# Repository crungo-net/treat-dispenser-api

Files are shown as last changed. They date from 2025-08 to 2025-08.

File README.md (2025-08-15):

# Treat Dispenser API

A simple REST API for controlling a treat dispenser, built with [Axum](https://github.com/tokio-rs/axum) and async Rust, and dedicated to my two rabbits.

## Table of Contents

- [Features](#features)
- [3D Printing](#3d-printing)
- [Hardware Requirements](#hardware-requirements)
- [Quick Setup](#quick-setup)
- [Installation](#installation)
- [Debian Package (Raspberry Pi, ARM64)](#debian-package-raspberry-pi-arm64)
- [Configuration](#configuration)
- [Environment Variables](#environment-variables)
- [Justfile Commands](#justfile-commands)
- [Endpoints](#endpoints)
- [Hardware Integration](#hardware-integration)
- [Logging](#logging)
- [Code Structure](#code-structure)
- [Power Monitoring (INA219 Support)](#power-monitoring-ina219-support)
- [Weight Sensor (HX711 Support)](#weight-sensor-hx711-support)
- [Testing](#testing)
- [Continuous Integration (CI)](#continuous-integration-ci)
- [GitLab and GitHub: Why Both?](#gitlab-and-github-why-both)
- [Roadmap](#roadmap)
- [License](#license)

## Features

- **One-click treat dispensing:** Trigger treat dispensing remotely via a simple REST API call.
- **Secure access with JWT authentication:** Only authorized users can dispense treats or access sensitive endpoints.
- **Real-time status monitoring:** Instantly check dispenser health, motor status, uptime, power usage, and remaining treat weight.
- **Live power and current monitoring:** View live voltage, current, and power usage for hardware safety and diagnostics.
- **Weight monitoring with HX711 load cell:** Live grams remaining exposed in `/status`, with tare and scale calibration via `/tare` and `/calibrate` (calibration persisted on disk).
- **Automatic jam and error detection:** Detects jams, over‑current, and calibration failures; can cancel operations to protect hardware.
- **Pluggable hardware via config.yaml:** Select motor, power sensor, and weight sensor implementations without recompiling.
- **Supports multiple stepper motors:** Easily switch between 28BYJ-48, NEMA-14, or mock motors.
- **Configurable cooldown & current limits:** Prevent overheating or over‑current conditions.
- **Easy setup & deployment:** Debian package, Docker, and simple YAML configuration.
- **Structured logging and diagnostics.**
- **Web and mobile friendly.**

<p align="center">
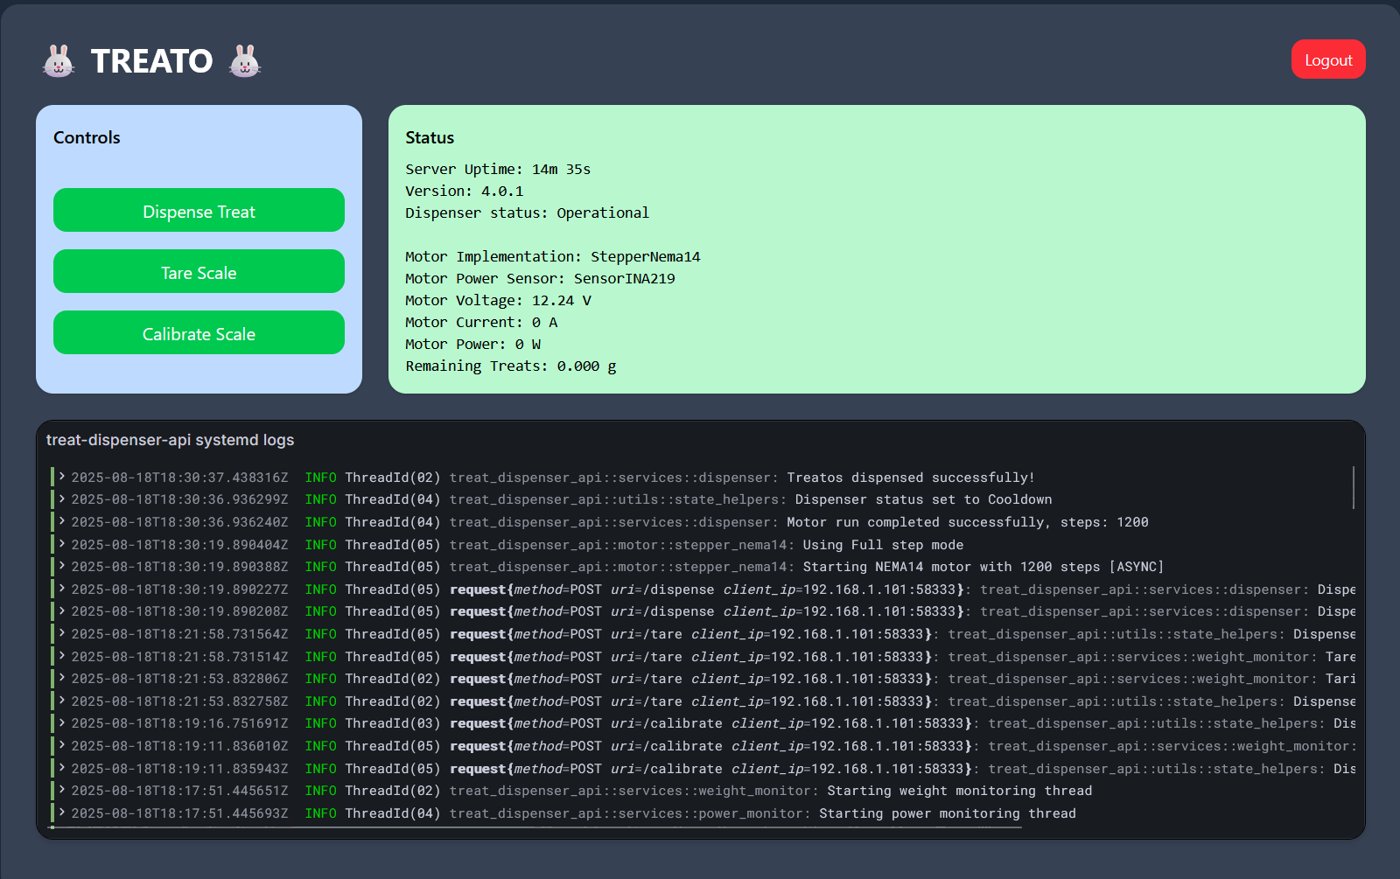
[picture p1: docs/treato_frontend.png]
Sample Treat Dispenser Frontend
  
</p>
<p align="center"><em>Simple monitoring frontend for the treat dispenser built with React (see <code>treat-dispenser-frontend</code> for source)</em></p>

## 3D Printing

STL files for 3D printing the dispenser hardware are available in the `3d_printing` folder of this repository. These models are heavily modified and based on the original pellet dispenser designs by [jackpkenn](https://github.com/jackpkenn/PelletDispenser/tree/master). Please review and adapt as needed for your hardware setup.

## Hardware Requirements

This project is designed to work with the following hardware:

- **NEMA14 stepper motor** (with A4988 or compatible driver)
- **INA219 sensor** (optional; for current, voltage, and power monitoring via I2C)
- **Load cell + HX711** (optional; for weight-based treat level monitoring)
- **Raspberry Pi** (recommended), or any microcontroller or ARM64 single-board computer with GPIO and I2C support

<p align="center">
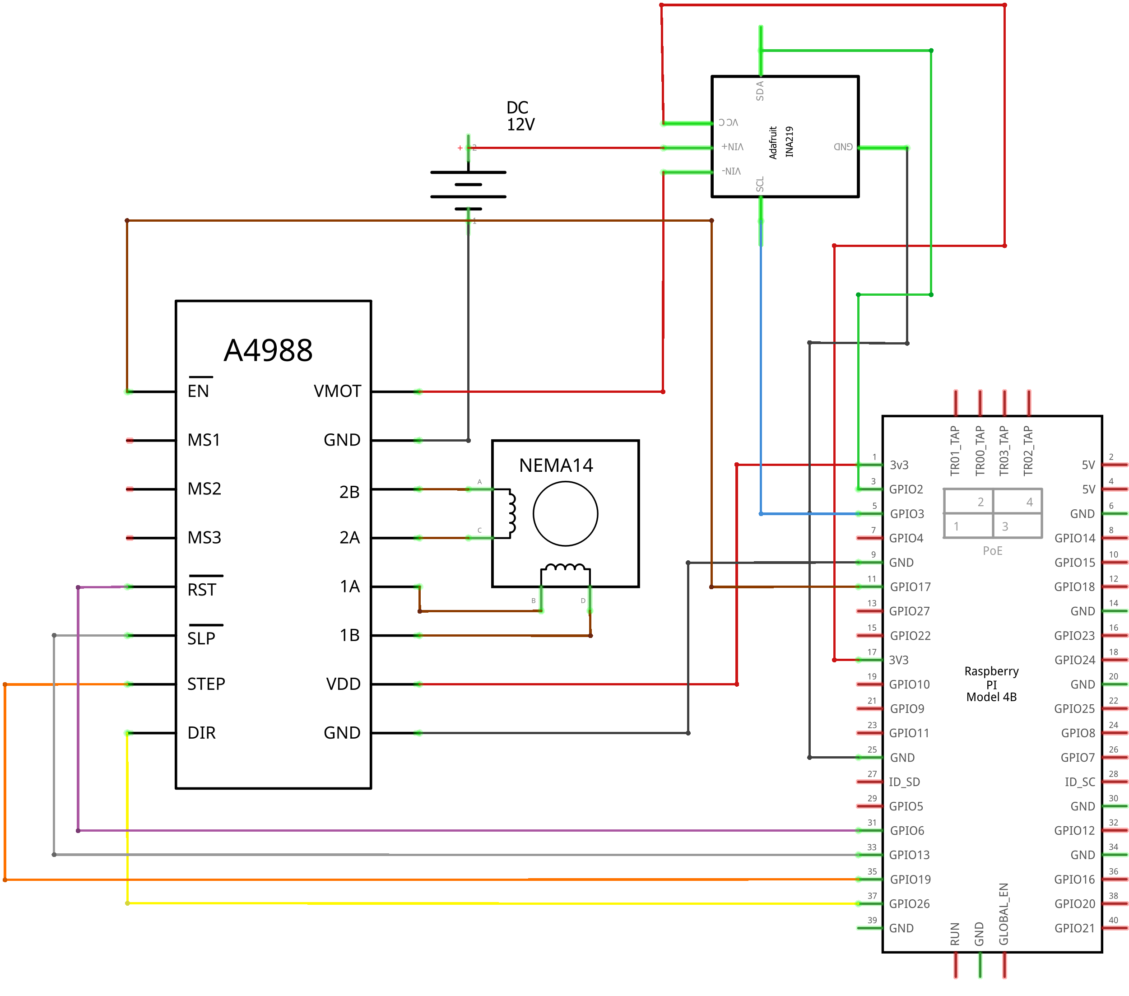
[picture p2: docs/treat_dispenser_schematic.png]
Treat Dispenser Wiring Diagram
  
</p>
<p align="center"><em>Wiring for the intended NEMA14/A4988 configuration</em></p>

Ensure your hardware is compatible with the provided 3D printed parts.
Other stepper motors and sensors may be supported with code modifications by implementing the AsyncStepperMotor and PowerSensor traits (interfaces). See the Hardware Integration section for more information. 

## Quick Setup

For a quick development environment setup, run:

```bash
chmod +x setup_dev_env.sh
./setup_dev_env.sh
```

## Installation

1. **Clone the repository**

2. **Install configuration files**
   ```sh
   sudo mkdir -p /etc/treat-dispenser-api
   sudo cp config/config.yaml /etc/treat-dispenser-api/
   ```

3. **Build and install the binary**
   ```sh
   cargo build --release
   sudo cp target/release/treat-dispenser-api /usr/local/bin/
   ```

## Debian Package (Raspberry Pi, ARM64)

Pre-built `.deb` packages for Raspberry Pi (arm64) are produced by the CI pipeline and can be found in the project releases or CI artifacts (see the `dist/` directory).

### Download and Install

1. **Download the latest `.deb` package**
   - From the [GitHub Releases](https://github.com/crungo-net/treat-dispenser-api/releases) page, or
   - From your CI/CD pipeline's `dist/` artifacts

2. **Copy the package to your Raspberry Pi**
   ```sh
   scp treat-dispenser-api_*_arm64.deb pi@raspberrypi.local:~
   # or use wget/curl to download directly on the Pi
   ```

3. **Install the package**
   ```sh
   sudo dpkg -i treat-dispenser-api_*_arm64.deb
   sudo systemctl restart treat-dispenser-api
   ```

- The service will start automatically and be enabled on boot.
- Configuration files are installed to `/etc/treat-dispenser-api/`.
- Logs are available via `journalctl -u treat-dispenser-api`.

### Upgrading

To upgrade, simply install the new `.deb` package with `dpkg -i` as above. Your configuration files will be preserved unless you remove the package with `--purge`.

## Configuration

All runtime hardware and safety behavior is configured in a single YAML file (default path: `/etc/treat-dispenser-api/config.yaml`). Environment variables are now only used for logging verbosity and the JWT secret.

### Configuration File Structure

`config/config.yaml` (example shipped with the repo):
```yaml
api:
  listen_address: "0.0.0.0:3500"   # Host:port the API binds to
  admin_user: "admin"              # Login username (change in production)
  admin_password: "password"       # Login password (change in production)

motor:
  motor_type: "StepperMock"        # One of: StepperMock | Stepper28BYJ48 | StepperNema14
  cooldown_ms: 5000                 # Minimum ms between dispense operations
  #nema14:                          # Uncomment to enable NEMA14 (A4988) pins
  #  dir_pin: 26
  #  step_pin: 19
  #  sleep_pin: 13
  #  reset_pin: 6
  #  enable_pin: 17

power_monitor:
  sensor: "SensorINA219"           # SensorINA219 | SensorMock
  motor_current_limit_amps: 0.7     # If rolling average exceeds, dispensing is cancelled

weight_monitor:
  sensor: "SensorMock"             # SensorHX711 | SensorMock
```

### Key Sections

- `api` – Network binding and admin credentials (used by `/login`).
- `motor` – Active motor implementation and (optionally) NEMA14 GPIO pin mapping plus dispense cooldown.
- `power_monitor` – Power sensor implementation and safety current threshold (amps). Over‑current triggers cancellation & state update.
- `weight_monitor` – Weight sensor implementation (mock or HX711). Calibration state is persisted separately to `/etc/treat-dispenser-api/weight_sensor_calibration.json`.

### Changing Hardware

Edit the corresponding `sensor` or `motor_type` field then restart the service:
```sh
sudo systemctl restart treat-dispenser-api
```
If switching to `StepperNema14`, ensure the `nema14` subsection is present and populated.

## Environment Variables

Only a minimal set is currently recognized:

| Variable | Description | Default |
|---|---|---|
| `RUST_LOG` | Log level (`trace`..`error`) | `info`  |
| `DISPENSER_JWT_SECRET` | Secret used to encode/decode JWT | (required) |

(Older `MOTOR_TYPE`, `POWER_SENSOR`, `WEIGHT_SENSOR` env vars have been superseded by the YAML configuration and are ignored.)

Example (optional) `.env` just for logging:
```
RUST_LOG=debug
```

## Justfile Commands

This project uses [`just`](https://github.com/casey/just) as a command runner. Install `just` (if not already installed) and use the following commands for common tasks:

- **Build ARM64 binary:**
  ```sh
  just build-arm64-binary
  ```
  Builds a release binary for ARM64.

- **Build Debian package:**
  ```sh
  just build-deb-package
  ```
  Builds the ARM64 binary and then creates a `.deb` package for deployment.

- **Run tests:**
  ```sh
  just test
  ```
  Runs all tests with output shown.

- **Download latest .deb release:**
  ```sh
  just get-latest-deb-release
  ```
  Downloads the latest `.deb` package from GitHub releases into the `dist/` directory.

You can view all available commands by running:
```sh
just --list
```

## Endpoints

### `GET /`

Returns a simple status message.

**Example:**
```sh
curl http://localhost:3500/
```
_Response:_
```
Treat dispenser is online! Binky time!
```

---

### `POST /dispense`

Dispenses a treat.  
**Requires** an `Authorization` header with a bearer token.

**Example:**
```sh
curl -H "Authorization: Bearer <YOUR_TOKEN>" http://localhost:3500/dispense
```

_Response:_
- `Dispensing started, please wait...` on success
- Error message with appropriate status code on failure

---

### `POST /cancel`

Cancels an ongoing dispensing operation.  
**Requires** an `Authorization` header with a bearer token.

**Example:**
```sh
curl -H "Authorization: Bearer <YOUR_TOKEN>" http://localhost:3500/cancel
```

_Response:_
- `Dispensing cancelled successfully.` on success
- Error message with appropriate status code if there is no active dispensing operation

**Notes:**
- If dispensing is in progress, this endpoint will immediately stop the motor and set the dispenser status to `Cancelled`.
- If no dispensing is active, an error is returned.

---

### `GET /status`

Returns detailed health status information including GPIO availability, motor status, uptime, power readings, and current weight reading (`remaining_treats_grams`).

**Example:**
```sh
curl http://localhost:3500/status
```

_Response:_ JSON object containing system status information.

---

### `POST /login`

Authenticates a user and returns a JWT token for use with protected endpoints.

**Request Body:**
```json
{
  "username": "admin",
  "password": "admin123"
}
```

**Example:**
```sh
curl -X POST http://localhost:3500/login \
  -H "Content-Type: application/json" \
  -d '{"username": "admin", "password": "admin123"}'
```

**Response:**
```json
{
  "token": "<JWT_TOKEN>",
  "expires_at": 1725580800
}
```

- Use the returned JWT token in the `Authorization` header as `Bearer <JWT_TOKEN>` for all protected endpoints (e.g., `/dispense`, `/cancel`).
- The default credentials are set in the config file (`admin_user`, `admin_password`). Change these for production.
- The token expires 7 days after provisioning.

---

### `POST /tare`

Tares (zeros) the weight sensor. Run this with an empty platform.  
**Requires** an `Authorization` header with a bearer token.

**Example:**
```sh
curl -X POST http://localhost:3500/tare \
  -H "Authorization: Bearer <YOUR_TOKEN>"
```

_Response:_ JSON object containing a human-readable message and the updated calibration state.

---

### `POST /calibrate`

Calibrates the weight sensor using a known mass placed on the platform. Call after a successful `/tare`.  
**Requires** an `Authorization` header with a bearer token.

**Request Body:**
```json
{ "known_mass_grams": 100.0 }
```

**Example:**
```sh
curl -X POST http://localhost:3500/calibrate \
  -H "Authorization: Bearer <YOUR_TOKEN>" \
  -H "Content-Type: application/json" \
  -d '{"known_mass_grams": 100.0}'
```

_Response:_ JSON object containing a human-readable message and the updated calibration state (including the computed scale factor).

## Hardware Integration

The application is designed primarily for the **NEMA14 stepper motor** (with A4988 or compatible driver), offering robust and reliable dispensing performance. 

The NEMA14 motor:
- Has 200 steps per full rotation (1.8° per step)
- Currently supports full-step mode only
- Requires proper power supply for the A4988 driver (DC 12V 2A)

To use the NEMA14 motor, see [Configuration](#configuration)

**Extensible Motor Support:**
Thanks to the trait-based architecture in [`src/motor`](src/motor), additional stepper motors and drivers can be supported with minimal code changes. You can add new motor implementations by following the existing trait pattern.

### 28BYJ-48 (Legacy/Secondary Support)

The application also supports the 28BYJ-48 stepper motor (with ULN2003 driver) as a secondary (and cheaper) option. Default pin configuration:

- Pin 26: Motor coil 1
- Pin 19: Motor coil 2
- Pin 13: Motor coil 3
- Pin 6: Motor coil 4

Supported step modes for 28BYJ-48:
- **Full step** (2048 steps per rotation, more torque, slower to avoid overheating)
- **Half step** (4096 steps per rotation, smoother motion)

Other step modes (quarter, eighth, sixteenth) are defined but not implemented for this motor.

## Logging

- Logs are output to stdout with thread IDs and names included.
- Log level can be set with the `RUST_LOG` environment variable (default: `info`).
- Example:  
  ```sh
  RUST_LOG=debug cargo run
  ```

## Code Structure

- `src/main.rs` – Application entry point, sets up routes, logging, server, and power monitoring thread.
- `src/lib.rs` – Library exports, app factory, and power monitoring thread starter.
- `src/application_state.rs` – Centralized application state and initialization logic.
- `src/error.rs` – Error types and HTTP response mapping.

- `src/motor/` – Stepper motor trait, real and mock implementations, and motor selection logic.
    - `mod.rs` – Motor trait and module exports
    - `stepper_28byj48.rs` – 28BYJ-48 motor implementation for ULN2003 driver
    - `stepper_nema14.rs` – NEMA-14 motor implementation for A4988 driver
    - `stepper_mock.rs` – Mock motor for testing and fallback

- `src/services/` – Business logic layer (hardware control, treat dispensing, status, authentication, etc.)
    - `mod.rs` – Exports service modules
    - `dispenser.rs` – Treat dispensing logic
    - `status.rs` – Status and health check logic
    - `auth.rs` – Authentication and JWT logic
    - `power_monitor.rs` – Power monitoring and alert logic
    - `weight_monitor.rs` – Weight sampling, tare/scale calibration, and calibration persistence

- `src/routes/` – API route handlers (HTTP endpoints)
    - `mod.rs` – Exports route modules
    - `dispense.rs` – Dispense endpoint handler
    - `status.rs` – Status endpoint handler
    - `auth.rs` – Login endpoint handler
    - `sensors.rs` – Weight sensor tare and calibration handlers

- `src/middleware/` – API middleware (e.g., authentication)
    - `mod.rs` – Exports middleware modules
    - `auth.rs` – Authentication middleware

- `src/sensors/` – Sensor integration
    - `mod.rs` – Exports sensor modules
    - `sensor_ina219.rs` – INA219 power/current/voltage monitoring via I2C
    - `sensor_hx711.rs` – HX711 load-cell support over SPI (via `hx711_spi` and `rppal`)
    - `sensor_mock.rs` - Mock sensor implementation for testing

- `src/utils/` – Utility functions and helpers
    - `mod.rs` – Exports utility modules
    - `datetime.rs` – Date/time formatting utilities
    - `filesystem.rs` – File system operations and path handling
    - `state_helpers.rs` – State manipulation helpers

This structure separates business logic, hardware integration, HTTP interface, sensor monitoring, and utility functions for clarity and maintainability. Each module has a single responsibility, making the codebase easier to test and extend as new features are added.

## Power Monitoring (INA219 Support)

The API supports real-time power, voltage, and current monitoring using the INA219 sensor via I2C:

- **INA219 Integration:**
  - Implemented in `src/sensors/sensor_ina219.rs` and exposed via `src/sensors/mod.rs`.
  - Uses the [`ina219`](https://crates.io/crates/ina219) crate and `linux-embedded-hal` for I2C communication.
  - Initializes the sensor on `/dev/i2c-1` (default address `0x40`).
  - Calibrates for 1A resolution and 0.1Ω shunt resistor (configurable in code).
  - Provides bus voltage, current, and calculated power readings.

- **Power Monitoring Logic:**
  - The `PowerMonitor` struct in `src/services/power_monitor.rs` collects and averages power readings.
  - The monitoring thread is started by calling `start_power_monitoring_thread` (now located in `src/services/power_monitor.rs`).
  - The thread polls the INA219 sensor every 100ms, adds readings to the monitor, and publishes them to the application state via a broadcast channel.
  - If the average current exceeds a threshold (default: 0.7A), the thread will log a warning and cancel ongoing motor operations for safety.
  - Readings are periodically cleared to avoid unbounded memory growth.

- **API Exposure:**
  - Power readings are published to the application state and exposed via the `/status` endpoint.
  - Status response includes:
    - `motor_voltage_volts`
    - `motor_current_amps`
    - `motor_power_watts`
  - If the sensor is unavailable, dummy values are returned and errors are logged.

- **Error Handling:**
  - Initialization and read errors are logged.
  - Sensor failures do not crash the API; fallback values are used.

## Weight Sensor (HX711 Support)

The API can read a load cell through an HX711 ADC using SPI via the `hx711_spi` crate and `rppal`:

- Uses Raspberry Pi SPI0 (Bus 0, CE0), SPI mode 1, ~1MHz.
- Typical wiring (verify with your board and the `hx711_spi` docs):
  - HX711 `DOUT` → Raspberry Pi `MISO` (SPI0 MISO)
  - HX711 `PD_SCK` → Raspberry Pi `MOSI` (SPI0 SCLK)
- Enable with: `WEIGHT_SENSOR=SensorHX711` (default is `SensorMock`).
- Current weight reading is exposed in `/status` as `remaining_treats_grams`.
- Calibration is persisted to `/etc/treat-dispenser-api/weight_sensor_calibration.json`.

This project was developed with the Adafruit HX711 board.

### Calibration Workflow

1. Ensure the platform is empty, then tare:
   ```sh
   curl -X POST http://localhost:3500/tare \
     -H "Authorization: Bearer <YOUR_TOKEN>"
   ```
2. Place a known mass (e.g., 100g) on the platform, then calibrate:
   ```sh
   curl -X POST http://localhost:3500/calibrate \
     -H "Authorization: Bearer <YOUR_TOKEN>" \
     -H "Content-Type: application/json" \
     -d '{"known_mass_grams": 100.0}'
   ```

Both endpoints return a message and the updated calibration values. Sampling pauses during calibration and automatically resumes afterward.

## Testing

The project includes both unit tests and integration tests:

### Unit Tests

Run unit tests with:
```sh
cargo test --lib
```

Unit tests cover individual components like date formatting utilities, motor control logic, and error handling.

### Integration Tests

Run integration tests with:
```sh
cargo test --test integration
```

Integration tests verify the full API functionality by starting a test server and making HTTP requests to the endpoints.

For better test parallelism, tests that require sequential execution (like testing busy states) are grouped together in single test functions.

## Continuous Integration (CI)

This project uses a GitLab CI pipeline (see `.gitlab-ci.yml`) to automate testing, building, packaging, and releasing for multiple architectures.

**Key pipeline stages:**

- **Test:**
  - Runs all tests (`cargo test --all --locked --release`) on every branch push.

- **Build:**
  - `build-amd64-binary-and-image`: Builds the x86_64 (amd64) binary and Docker image using BuildKit, pushes images to the private registry (`harbor.crungo.net`), and saves the binary as an artifact.
  - `build-arm64-binary`: Builds the ARM64 binary (`aarch64-unknown-linux-musl`) and saves it as an artifact.
  - `build-deb-package`: Creates a `.deb` package for ARM64 using the prebuilt binary and saves it as an artifact.

- **Tag:**
  - `tag-release`: (Manual, on `main` branch) Tags the commit with the version from `Cargo.toml` and pushes the tag to the repository.

- **Fetch:**
  - `fetch-artifacts-for-tag`: Fetches build artifacts for a release tag using the GitLab CLI, ensuring all necessary files are available for deployment.

- **Deploy:**
  - `release-github`: Publishes the binaries and `.deb` package to GitHub Releases, generating a changelog from commit history.

**Artifacts:**
- Built binaries (`dist/treat-dispenser-api-amd64`, `dist/treat-dispenser-api-aarch64`) and `.deb` packages are saved as CI artifacts for one week and are used in the release process.

**Image Tags:**
- Docker images are tagged with `latest`, the short commit SHA, and the branch name for traceability.

**Authentication:**
- Docker credentials are injected for pushing to the private registry (`harbor.crungo.net`).
- GitHub and GitLab tokens are used for release automation.

**Multi-Arch Support:**
- Both x86_64 and ARM64 binaries and images are built and published, supporting a wide range of deployment targets.

**Debian Packages:**
- The pipeline produces `.deb` packages for ARM64, suitable for Raspberry Pi and similar devices. These are available as artifacts and in GitHub Releases.

See the `.gitlab-ci.yml` file for full details and customization options.

## GitLab and GitHub: Why Both?

This project is maintained in both a private self-hosted GitLab repository and a public GitHub repository. The primary reason for this dual setup is to leverage private build infrastructure:

- **Private Docker Registry:** Container images are built and pushed to a secure, self-hosted Docker registry for internal deployments.
- **Kubernetes Runners:** CI/CD pipelines use private Kubernetes runners for builds and deployments.
- **Confidential Artifacts:** Some build artifacts and deployment configurations are kept private for security and operational reasons.

The public GitHub repository is used for open-source collaboration, issue tracking, and public releases, while the private GitLab instance handles sensitive infrastructure and deployment automation.

**Repository Mirroring:**
GitLab is configured to automatically mirror (push) all changes to GitHub using its built-in repository mirroring feature. This ensures that the public GitHub repository stays up to date with the latest changes from the private GitLab source.

## Roadmap

Planned features and improvements for future releases:

- **Camera integration:** Add support for a camera to monitor the dispenser or take photos/videos during dispensing.
- **Play Mexican jingles:** Play Mexican jingles through speakers for one of my bunnies (one of whom grew up with and loves them).

## License

MIT

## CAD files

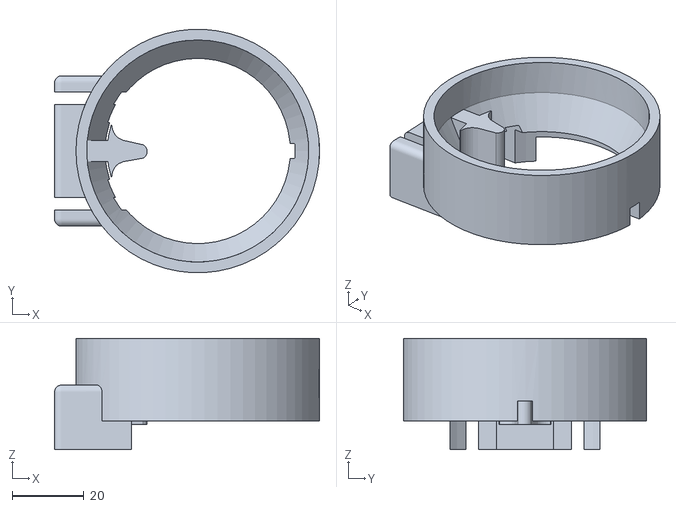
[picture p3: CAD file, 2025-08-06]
3d_printing/Lid V5.STL
74.0 x 67.9 x 31.0

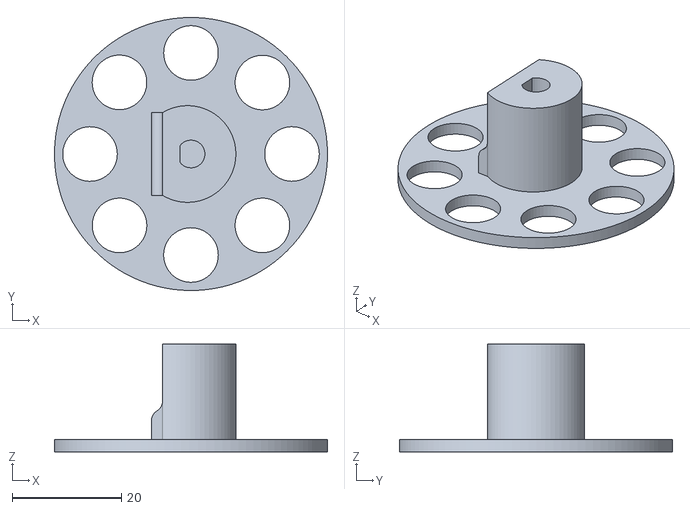
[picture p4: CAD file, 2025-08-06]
3d_printing/Rotor Custom - Readjusted Shaft Position v2.stl
50.0 x 50.0 x 19.8

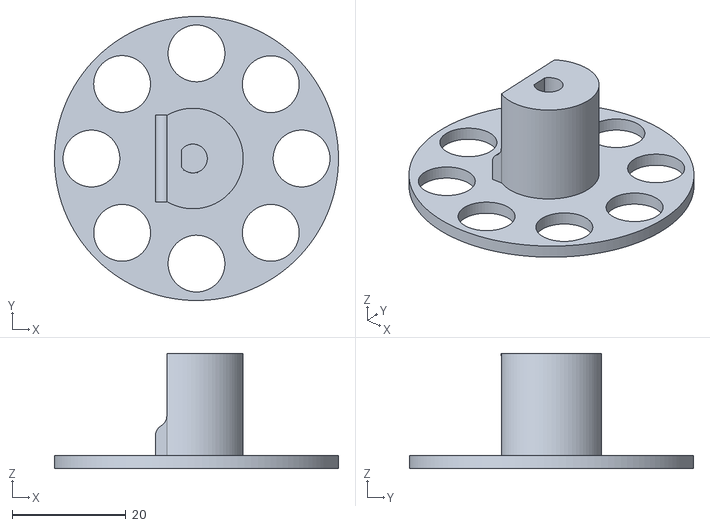
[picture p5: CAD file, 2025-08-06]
3d_printing/Rotor Custom v7.stl
50.0 x 50.0 x 20.3

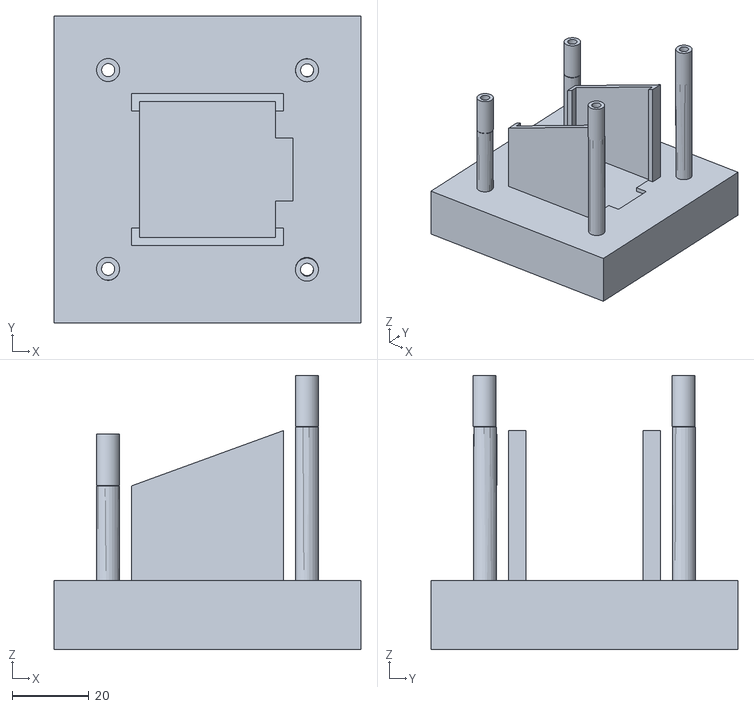
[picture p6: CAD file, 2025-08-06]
3d_printing/Motor Base.stl
80.0 x 80.0 x 71.5

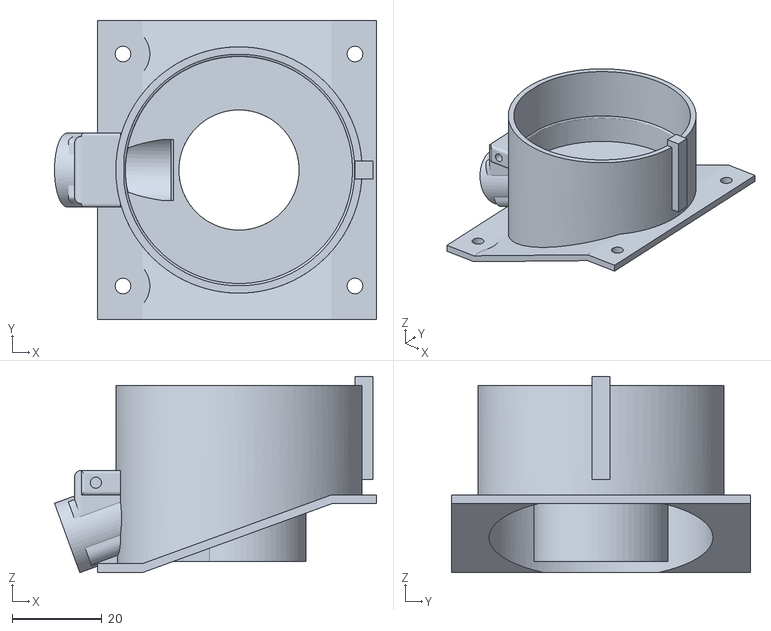
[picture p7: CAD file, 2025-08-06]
3d_printing/Base Custom Wide v2.stl
71.9 x 66.8 x 43.8

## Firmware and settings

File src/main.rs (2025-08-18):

use treat_dispenser_api::config::load_app_config;
use treat_dispenser_api::{
    build_app, configure_logging, services::power_monitor, services::weight_monitor, start_server,
};

#[tokio::main]
async fn main() {
    dotenv::dotenv().ok();

    configure_logging();

    let config = load_app_config();
    let (app_state, router) = build_app(config.clone());

    power_monitor::start_power_monitoring_thread(&app_state).await;
    weight_monitor::start_weight_monitoring_thread(&app_state).await;
    start_server(router, config).await;
}

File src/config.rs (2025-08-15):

use crate::utils;
use crate::motor::stepper_nema14::Nema14Config;

use tracing ::{debug};

pub const MOTOR_COOLDOWN_MS_DEFAULT: u64 = 5000;
pub const MOTOR_CURRENT_LIMIT_AMPS_DEFAULT: f32 = 0.7;

#[derive(serde::Deserialize, serde::Serialize, Debug, Clone)]
pub struct ApiConfig {
    pub listen_address: String,
    pub admin_user: String,
    pub admin_password: String,
}

#[derive(serde::Deserialize, serde::Serialize, Debug, Clone)]
pub struct PowerMonitorConfig {
    pub sensor: String,
    pub motor_current_limit_amps: Option<f32>,
}

#[derive(serde::Deserialize, serde::Serialize, Debug, Clone)]
pub struct WeightMonitorConfig {
    pub sensor: String,
}

#[derive(serde::Deserialize, serde::Serialize, Debug, Clone)]
pub struct MotorConfig {
    pub motor_type: String,
    pub nema14: Option<Nema14Config>,
    pub cooldown_ms: Option<u64>,
}

#[derive(serde::Deserialize, serde::Serialize, Debug, Clone)]
pub struct AppConfig {
    pub api: ApiConfig,
    pub motor: MotorConfig,
    pub power_monitor: PowerMonitorConfig,
    pub weight_monitor: WeightMonitorConfig,
}

pub fn load_app_config_from_str(config_str: &str) -> AppConfig {
    serde_yaml::from_str(config_str).expect("Failed to parse app config")
}

pub fn load_app_config() -> AppConfig {
    let app_config_path = utils::filesystem::get_config_path();
    let config_str = std::fs::read_to_string(&app_config_path).expect(&format!(
        "Failed to read app config file at {}",
        app_config_path
    ));

    let app_config: AppConfig = load_app_config_from_str(&config_str);

    // Log the config struct as json
    debug!(
        "Parsed app config: {}",
        serde_json::to_string(&app_config).unwrap_or_default()
    );
    app_config
}

#[cfg(test)]
mod tests {
    use super::*;   

    #[test]
    fn test_load_app_config() {
        let config_str = r#"
        api:
            listen_address: "0.0.0.0:3500"
            admin_user: "admin"
            admin_password: "password"

        motor:
            motor_type: "StepperNema14"
            cooldown_ms: 5000
            nema14:
              dir_pin: 26
              step_pin: 19
              sleep_pin: 13
              reset_pin: 6
              enable_pin: 17

        power_monitor:
            sensor: "SensorINA219"
            motor_current_limit_amps: 0.7

        weight_monitor:
            sensor: "SensorHX711"
        "# ;  

        let config = load_app_config_from_str(config_str);
        let nema14_config_opt = config.motor.nema14.clone();

        assert_eq!(config.api.listen_address, "0.0.0.0:3500");
        assert_eq!(config.api.admin_user, "admin");
        assert_eq!(config.api.admin_password, "password");
        assert_eq!(config.motor.motor_type, "StepperNema14");
        assert_eq!(config.motor.cooldown_ms, Some(5000));
        assert_eq!(config.power_monitor.sensor, "SensorINA219");
        assert_eq!(config.power_monitor.motor_current_limit_amps, Some(0.7));
        assert_eq!(config.weight_monitor.sensor, "SensorHX711");

        assert!(nema14_config_opt.is_some());
        let nema14_config = nema14_config_opt.unwrap();

        assert_eq!(nema14_config.dir_pin, 26);
        assert_eq!(nema14_config.step_pin, 19);
        assert_eq!(nema14_config.sleep_pin, 13);
        assert_eq!(nema14_config.reset_pin, 6);
        assert_eq!(nema14_config.enable_pin, 17);

    }
}

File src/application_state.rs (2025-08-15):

use rppal::gpio::Gpio;
use rppal::spi::Bus;
use rppal::spi::SlaveSelect;
use serde::Serialize;
use std::fmt;
use std::sync::Arc;
use std::sync::atomic::AtomicBool;
use std::time::SystemTime;
use tokio::sync::Mutex;
use tokio_util::sync::CancellationToken;
use tracing::{error, info, warn};

use crate::AppConfig;
use crate::motor::AsyncStepperMotor;
use crate::motor::stepper_28byj48::Stepper28BYJ48;
use crate::motor::stepper_mock::StepperMock;
use crate::motor::stepper_nema14::StepperNema14;
use crate::sensors::PowerReading;
use crate::sensors::PowerSensor;
use crate::sensors::WeightReading;
use crate::sensors::WeightSensor;
use crate::sensors::WeightSensorCalibration;
use crate::services::weight_monitor;

pub type AppStateMutex = Arc<Mutex<ApplicationState>>;

#[derive(Serialize, Debug, Clone, PartialEq)]
pub enum DispenserStatus {
    Dispensing,
    Operational,
    Jammed,
    Empty,
    Unknown,
    MotorControlError,
    NoGpio,
    Cooldown,
    Cancelled,
    Calibrating,
    CalibrationFailed,
}

impl fmt::Display for DispenserStatus {
    fn fmt(&self, f: &mut fmt::Formatter<'_>) -> fmt::Result {
        write!(f, "{:?}", self)
    }
}

pub struct ApplicationState {
    pub gpio: Option<Gpio>,
    pub status: DispenserStatus,
    pub startup_time: SystemTime,
    pub last_dispense_time: Option<String>,
    pub last_error_msg: Option<String>,
    pub last_error_time: Option<String>,
    pub last_step_index: Option<u32>,
    pub motor: Arc<Box<dyn AsyncStepperMotor + Send + Sync>>,
    pub app_config: AppConfig,
    pub version: String,
    pub power_sensor_mutex: Option<Arc<Mutex<Box<dyn PowerSensor>>>>,
    pub power_readings_tx: tokio::sync::watch::Sender<PowerReading>,
    pub power_readings_rx: tokio::sync::watch::Receiver<PowerReading>,
    pub motor_cancel_token: Option<CancellationToken>,
    pub weight_sensor_mutex: Option<Arc<Mutex<Box<dyn WeightSensor>>>>,
    pub weight_readings_tx: tokio::sync::watch::Sender<WeightReading>,
    pub weight_readings_rx: tokio::sync::watch::Receiver<WeightReading>,
    pub calibration_in_progress: Arc<AtomicBool>,
    pub calibration_tx: tokio::sync::watch::Sender<WeightSensorCalibration>,
    pub calibration_rx: tokio::sync::watch::Receiver<WeightSensorCalibration>,
}

impl ApplicationState {
    pub fn new(app_config: AppConfig) -> Self {
        let version = env!("CARGO_PKG_VERSION").to_string();
        let status: DispenserStatus;

        info!("Starting treat-dispenser-api, version: {}", version);

        let motor = match init_motor(&app_config) {
            Ok(motor) => {
                info!("Motor initialized: {}", motor.get_name());
                Arc::new(motor)
            }
            Err(e) => {
                error!("Failed to select motor: {}", e);
                std::process::exit(1);
            }
        };

        let power_sensor_mutex = match init_power_sensor(&app_config) {
            Ok(sensor) => Some(Arc::new(Mutex::new(sensor))),
            Err(e) => {
                error!("Failed to initialize power sensor: {}", e);
                None
            }
        };

        let (power_readings_tx, power_readings_rx) =
            tokio::sync::watch::channel(PowerReading::default());

        let gpio = match Gpio::new() {
            Ok(gpio) => {
                info!("GPIO initialized successfully");
                Some(gpio)
            }
            Err(e) => {
                warn!("Failed to initialize GPIO: {}", e);
                None
            }
        };

        if motor.requires_gpio() && gpio.is_none() {
            error!("Motor requires GPIO but GPIO initialization failed");
            status = DispenserStatus::NoGpio;
        } else {
            status = DispenserStatus::Operational;
        }

        let weight_sensor_result = init_weight_sensor(&app_config);
        let weight_sensor = match weight_sensor_result {
            Ok(sensor) => sensor,
            Err(e) => {
                error!("Failed to initialize weight sensor: {}", e);
                std::process::exit(1)
            }
        };

        let weight_sensor_mutex = Some(Arc::new(Mutex::new(weight_sensor)));
        let (weight_readings_tx, weight_readings_rx) =
            tokio::sync::watch::channel(WeightReading::default());

        let weight_sensor_calibration = weight_monitor::load_calibration_from_file()
            .unwrap_or_else(|e| {
                warn!("Failed to load weight sensor calibration from file, will use default values instead. Error: {}", e);
                WeightSensorCalibration::default()
            });

        let (calibration_tx, calibration_rx) =
            tokio::sync::watch::channel(weight_sensor_calibration);

        Self {
            gpio,
            status,
            startup_time: SystemTime::now(),
            last_dispense_time: None,
            last_error_msg: None,
            last_error_time: None,
            last_step_index: None,
            motor,
            app_config,
            version,
            power_sensor_mutex,
            power_readings_tx,
            power_readings_rx,
            weight_sensor_mutex,
            weight_readings_tx,
            weight_readings_rx,
            motor_cancel_token: None,
            calibration_in_progress: Arc::new(AtomicBool::new(false)),
            calibration_tx,
            calibration_rx,
        }
    }
}

fn init_weight_sensor(
    app_config: &AppConfig,
) -> Result<Box<dyn WeightSensor>, String> {
    match app_config.weight_monitor.sensor.as_str() {
        "SensorHX711" => {
            return Ok(Box::new(crate::sensors::sensor_hx711::SensorHx711::new(
                Bus::Spi0,
                SlaveSelect::Ss0,
            )?));
        }
        "SensorMock" => return Ok(Box::new(crate::sensors::sensor_mock::SensorMock::new())),
        _ => return Err(format!("Unsupported weight sensor type '{}'", app_config.weight_monitor.sensor)),
    };
}

fn init_power_sensor(
    app_config: &AppConfig,
) -> Result<Box<dyn PowerSensor>, String> {
    match app_config.power_monitor.sensor.as_str() {
        "SensorINA219" => return Ok(Box::new(crate::sensors::sensor_ina219::SensorIna219::new())),
        "SensorMock" => return Ok(Box::new(crate::sensors::sensor_mock::SensorMock::new())),
        _ => return Err(format!("Unsupported power sensor type '{}'", app_config.power_monitor.sensor)),
    };
}
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

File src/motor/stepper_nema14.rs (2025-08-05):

use crate::motor::{AsyncStepperMotor, Direction, StepMode, StepperMotor};

use crate::application_state::ApplicationState;
use rand::Rng;
use rand::SeedableRng;
use rand::rngs::StdRng;
use rppal::gpio::{Gpio, OutputPin};
use serde::{Deserialize, Serialize};
use std::sync::Arc;
use std::time::Duration;
use tokio::sync::Mutex;
use tokio_util::sync::CancellationToken;
use tracing::{debug, info};

pub struct StepperNema14 {
    config: Nema14Config,
}

impl StepperMotor for StepperNema14 {
    fn get_name(&self) -> String {
        "StepperNema14".to_string()
    }

    fn get_step_count_for_full_rotation(&self, _step_mode: &StepMode) -> u32 {
        200
    }

    fn run_motor(
        &self,
        steps: u32,
        direction: &Direction,
        step_mode: &StepMode,
        _app_state: &Arc<Mutex<ApplicationState>>,
    ) -> Result<u32, String> {
        info!("Starting NEMA14 motor with {} steps", steps);

        match step_mode {
            StepMode::Full => {
                // NEMA14 typically supports full and half step modes
                info!("Using {} step mode", step_mode);
            }
            _ => {
                return Err("Unsupported step mode for NEMA14".to_string());
            }
        }

        match Gpio::new() {
            Ok(_gpio) => {
                let mut step_pin = self.get_output_pin(self.config.step_pin)?;
                let mut dir_pin = self.get_output_pin(self.config.dir_pin)?;
                let mut sleep_pin = self.get_output_pin(self.config.sleep_pin)?;
                let mut reset_pin = self.get_output_pin(self.config.reset_pin)?;
                let mut enable_pin = self.get_output_pin(self.config.enable_pin)?;

                sleep_pin.write(rppal::gpio::Level::High);
                reset_pin.write(rppal::gpio::Level::High);
                enable_pin.write(rppal::gpio::Level::Low); // Enable the motor

                match direction {
                    Direction::Clockwise => dir_pin.write(rppal::gpio::Level::High),
                    Direction::CounterClockwise => dir_pin.write(rppal::gpio::Level::Low),
                }

                let step_speed_us = self.config.step_speed_us.or(Some(1000)).unwrap();

                let mut i = 0;
                let mut is_dir_high = match direction {
                    Direction::Clockwise => true,
                    Direction::CounterClockwise => false,
                };

                // randomize number of steps before toggling direction
                // we want to toggle direction pin every 110-200 steps (200 is full rotation), helps prevent treats from jamming
                let mut rng = rand::rng();
                let mut random_steps = rng.random_range(110..=200);

                for _step in 0..steps {
                    i += 1;
                    if i % random_steps == 0 {
                        if is_dir_high {
                            dir_pin.write(rppal::gpio::Level::Low);
                            is_dir_high = false;
                        } else {
                            dir_pin.write(rppal::gpio::Level::High);
                            is_dir_high = true;
                        }
                        debug!("Direction pin toggled at step {}", i);
                        i = 0; // Reset the counter after toggling
                        random_steps = rng.random_range(110..=200);
                    }

                    // pulse the step pin to move motor shaft
                    step_pin.write(rppal::gpio::Level::High);
                    std::thread::sleep(Duration::from_micros(step_speed_us));
                    step_pin.write(rppal::gpio::Level::Low);
                    std::thread::sleep(Duration::from_micros(step_speed_us));
                }

                // Disables the motor after operation
                enable_pin.write(rppal::gpio::Level::High);
                Ok(steps)
            }
            Err(e) => {
                return Err(format!("Failed to initialize GPIO: {}", e));
            }
        }
    }

    fn run_motor_degrees(
        &self,
        degrees: f32,
        direction: &Direction,
        step_mode: &StepMode,
        app_state: &Arc<Mutex<ApplicationState>>,
    ) -> Result<u32, String> {
        self.run_motor((degrees / 1.80) as u32, direction, step_mode, app_state)
    }

    fn as_any(&self) -> &dyn std::any::Any {
        self
    }
}

#[async_trait::async_trait]
impl AsyncStepperMotor for StepperNema14 {
    async fn run_motor_degrees_async(
        &self,
        degrees: f32,
        direction: &Direction,
        step_mode: &StepMode,
        _app_state: &Arc<Mutex<ApplicationState>>,
        cancel_token: &CancellationToken,
    ) -> Result<u32, String> {
        let steps = (degrees / 1.80) as u32;
        info!("Starting NEMA14 motor with {} steps [ASYNC]", steps);

        match step_mode {
            StepMode::Full => {
                // NEMA14 typically supports full and half step modes
                info!("Using {} step mode", step_mode);
            }
            _ => {
                return Err("Unsupported step mode for NEMA14".to_string());
            }
        }

        match Gpio::new() {
            Ok(_gpio) => {
                let mut step_pin = self.get_output_pin(self.config.step_pin)?;
                let mut dir_pin = self.get_output_pin(self.config.dir_pin)?;
                let mut sleep_pin = self.get_output_pin(self.config.sleep_pin)?;
                let mut reset_pin = self.get_output_pin(self.config.reset_pin)?;
                let mut enable_pin = self.get_output_pin(self.config.enable_pin)?;

                sleep_pin.write(rppal::gpio::Level::High);
                reset_pin.write(rppal::gpio::Level::High);
                enable_pin.write(rppal::gpio::Level::Low); // Enable the motor

                match direction {
                    Direction::Clockwise => dir_pin.write(rppal::gpio::Level::High),
                    Direction::CounterClockwise => dir_pin.write(rppal::gpio::Level::Low),
                }

                let step_speed_us = self.config.step_speed_us.or(Some(1000)).unwrap();

                let mut i = 0;
                let mut is_dir_high = match direction {
                    Direction::Clockwise => true,
                    Direction::CounterClockwise => false,
                };

                // randomize number of steps before toggling direction
                // we want to toggle direction pin every 110-200 steps (200 is full rotation), helps prevent treats from jamming
                let mut rng = StdRng::from_os_rng();
                let mut random_steps = rng.random_range(110..=200);

                for _step in 0..steps {
                    if cancel_token.is_cancelled() {
                        info!("Received cancellation request, stopping motor operation.");
                        return Err("Motor run cancelled".to_string());
                    }
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

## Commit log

2025-07-05 add readme, return detailed error message when dispense fails
    [main.rs]
2025-07-10 Basic motor control in background thread
2025-07-10 Refactor motor logic, improve logging
2025-07-10 use pattern matching on device state instead of checking for gpio directly
2025-07-10 Use full step sequence for more torque, update readme
2025-07-11 Support multiple motor types, allow runtime implementation selection
2025-07-12 Record last error, add arm64 build to published releases
    [state.rs]
2025-07-12 allow movement by a specified number of degrees, track last step index
2025-07-13 - Decouple driver interface from state management - Clean up todos/comments - Use type aliases to decrease verbosity
2025-07-14 feat: log instantianted stepper implementation
2025-07-14 chore: add more granular stages
2025-07-14 chore: check if current commit is appropriately tagged
2025-07-14 chore: rename amd64 build job, pin rust version for arm64 job
2025-07-15 fix: gracefully handle DISPENSER_API_TOKEN not being set by user, previously panicked test: add basic tests for all endpoints
    [dispenser.rs, integration.rs, main.rs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]
2025-07-15 refactor: store motor in state
2025-07-15 test: use mock motor in tests
2025-07-15 test: add delay to simulate motor operation
2025-07-15 test: check motor busy response from dispense endpoint
2025-07-15 refactor: split motor.rs into granular modules for clearer organization test: increase wait time before checking for server uptime
2025-07-16 test: check device status after various operations
2025-07-16 refactor: move pin initialization functions to utils module
2025-07-16 chore: update pipeline to retry builds in case of transient infrastructure issues like kubernetes etcd timeouts
2025-07-19 feat: add support for nema14 stepper motor
2025-07-19 refactor: move nema-14 pin init to functions
2025-07-19 fix: direction handling for nema14, use enable pin instead of sleep/reset
    [stepper_nema14.rs]
2025-07-19 feat: read motor config from yaml
2025-07-20 refactor: reduce repitition for StepperNema14 interface
2025-07-26 feat: reverse direction occasionally to help prevent jams / chore: bump version to 1.2.0
    [dispenser.rs, stepper_nema14.rs]
2025-07-30 feat: show motor name in /status response; chore: clean up logging
2025-07-31 feat: wip support for ina219 current monitor; chore: bump version to 1.4.0
2025-08-01 feat: working current and voltage readings from ina219
2025-08-01 refactor: thread safety for ina219 sensor
2025-08-01 feat: display power readings in status response; chore: update justfile to copy locally built deb package to nas
2025-08-02 feat: exception handling for power readings in /status response
2025-08-02 test: check power readings
2025-08-02 refactor: use pub-sub model for power readings from ina219 sensor; chore: bump version to 1.4.1, rename modules
2025-08-02 refactor: avoid holding onto lock for longer than necessary for /status endpoint
    [power_monitor.rs, status.rs]
2025-08-03 feat: log 401/429/503 as warnings instead of error; chore: clean up formatting and log levels
    [application_state.rs, dispenser.rs, integration.rs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]
2025-08-04 feat: interleave power readings during motor operation
2025-08-05 fix: change method from get -> post for appropriate endpoints
    [integration.rs]
2025-08-05 feat: implement jwt login flow; chore: bump version to 3.0.0
2025-08-05 test: weave new login flow into existing tests
2025-08-05 refactor: reorganize power monitor related objects and functions
2025-08-05 refactor: move PowerReading to separate module
2025-08-05 feat: add software detection of overcurrent, cancel motor operations if current exceeds threshold
2025-08-05 test: add unit tests for PowerMonitor
2025-08-05 feat: use dependency injection to allow mock power sensors
2025-08-05 test: use mock power sensor for tests
2025-08-05 chore: update readme, log average current from power monitoring thread
2025-08-05 fix: clamp current readings to prevent sensor glitches from skewing calculations
    [sensor_ina219.rs]
2025-08-06 refactor: switch to tokio::sync::watch from sync::broadcast for power monitoring channel, improving performance by allowing subscribers to use the last published value instead of waiting for the next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
2025-08-06 refactor: clean up error handling for nema14 init routine
    [application_state.rs]
2025-08-06 chore: update readme, adjust .deb pre-installed config file to include default admin credentials, add STLs for 3d printing
    [Base Custom Wide v2.stl, Lid V5.STL, Motor Base.stl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]
2025-08-07 chore: update readme to show sample frontend
2025-08-07 chore: add wiring diagram
2025-08-07 chore: use png instead of svg for schematic
2025-08-10 feat: wip support for hx711 loadcell adc
2025-08-11 feat: implement taring for weight sensor
2025-08-11 feat: add mock weight sensor
2025-08-11 feat: wip calculate scale factor for weight sensor
2025-08-11 feat: add /calibrate route
2025-08-11 feat: working weight sensor calibration
2025-08-11 feat: persist weight sensor calibration in json file on disk
2025-08-12 fix: set status to calibration during tare and scale factor computation
2025-08-12 fix: clamp weight reading to 0 if negative or very small
    [sensor_hx711.rs]
2025-08-12 chore: update readme to mention specific HX711 board that was used for development
2025-08-12 fix: avoid cloning WeightSensorCalibration
    [sensor_hx711.rs]
2025-08-12 fix: use fp32 for weight reading instead of i32
    [integration.rs, mod.rs, sensor_hx711.rs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]
2025-08-14 fix: secure permissions for config file (deb install); refactor: move config code to its own module
    [config.rs, dispenser.rs, integration.rs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]
2025-08-15 fix: status check no longer waits for power readings, just uses latest published value
    [application_state.rs, integration.rs, status.rs]
2025-08-15 refactor: move power monitor, weight monitor, and motor config to file instead of env vars
2025-08-15 fix: remove nema14 from config root
    [application_state.rs, config.rs]
2025-08-15 fix: prevent taring/calibration of loadcell during motor operation
2025-08-18 fix: remove unnecessary cloning
    [integration.rs, main.rs, power_monitor.rs]
